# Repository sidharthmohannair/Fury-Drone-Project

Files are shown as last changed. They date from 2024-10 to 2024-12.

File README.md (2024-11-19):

# **Fury Drone Project**

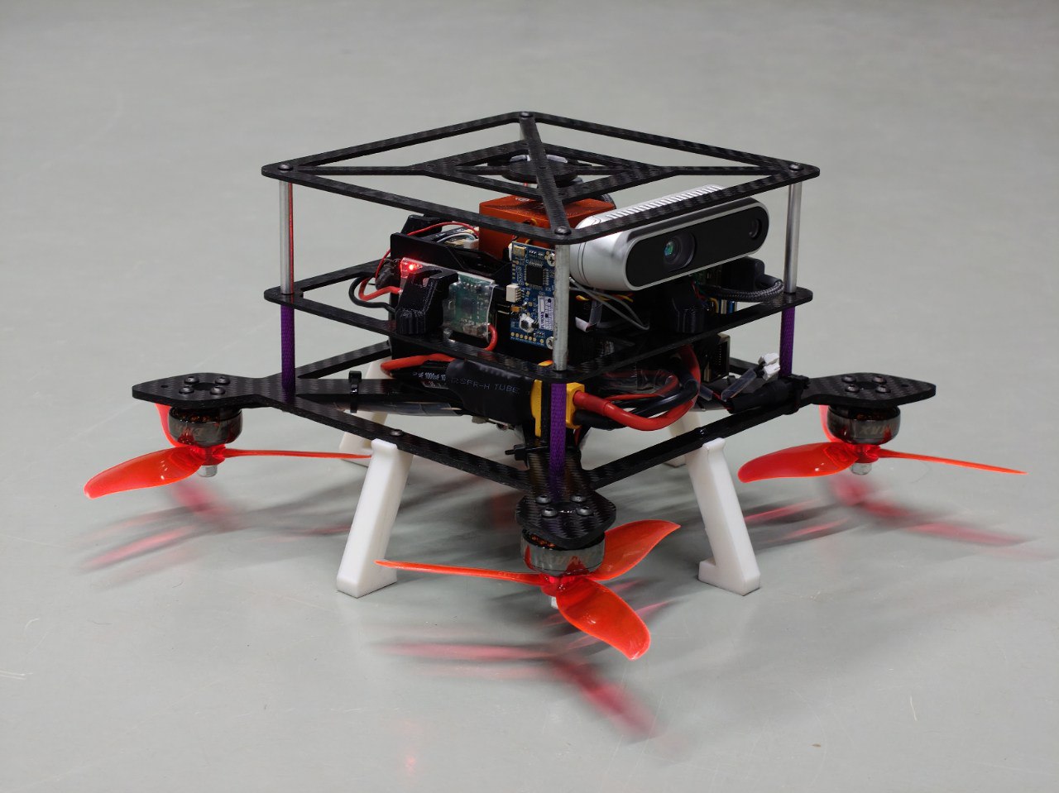
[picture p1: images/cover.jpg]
FuryVision AAV


Welcome to the **Fury Drone Project** repository! This project showcases the development of **Fury**, a high-performance, multi-mission **Autonomous Air Vehicle (AAV)** platform designed for various aerial missions, incorporating advanced sensors and components.

The repository contains everything you need to build, modify, and fly the **Fury Drone**, including design files, firmware, software, and documentation for multiple versions of the drone.

## **Overview**

The **Fury Drone** is engineered to push the boundaries of **unmanned aerial systems (UAS)** technology. It integrates components such as the **Pixhawk Orange Cube+ flight controller**, **Intel RealSense cameras**, **Emax brushless motors**, and **Here 3+ GPS module** for precise navigation and mission versatility.

This repository covers:
- **Original Fury Drone**: Developed as the core platform for high-performance UAS missions, the original version was designed by **SPIN Laboratory, Dept. of Electrical Engineering, IIT Kanpur**.
- **FuryVision AAV**: A modified version designed to accommodate **four Intel RealSense cameras** for enhanced visual and spatial sensing. This version was developed by the **Open Drone Team, CDOH Lab, ICFOSS, Thiruvananthapuram**, based on the requirements specified by IIT Kanpur.

---

## **Versions**

This repository contains two main versions of the Fury drone:

1. **Original Fury Drone**  
   - The foundational version of the Fury platform, designed for general high-performance UAS missions.
   - Developed by **SPIN Laboratory, Dept. of Electrical Engineering, IIT Kanpur**.
   - This version features basic flight capabilities using the **Pixhawk Orange Cube+** and standard UAS components.

2. [**FuryVision AAV**](/versions/2_furyvision_aav/README.md)  
   - An upgraded version of the Fury drone, modified to mount and integrate **four Intel RealSense cameras** for enhanced visual and spatial sensing.
   - Developed by the **Open Drone Team, CDOH Lab, ICFOSS, Thiruvananthapuram**, based on requirements specified by **IIT Kanpur**.
   - Includes advanced capabilities for visual sensing, spatial mapping, and autonomous navigation.

Each version has its own folder within the `versions/` directory, containing specific design files, firmware, and instructions.

---

## **Getting Started**

To get started with building and flying the **Fury Drone**, follow these steps:

### 1. **Clone the Repository**
   ```bash
   git clone https://github.com/sidharthmohannair/Fury-Drone-Project.git

   cd Furry-Drone-Project
   ```

### 2. **Choose a Version**
   Navigate to the version you're interested in:
   - For the original version: `versions/original_fury/`
   - For the modified version: `versions/furyvision_aav/`

### 3. **Follow the Setup Instructions**
   Refer to the detailed setup guides in the **`INSTALLATION.md`** and **`assembly_instructions.md`** files for each version.

### 4. **Upload Firmware**
   Upload the appropriate firmware for the version you’re working on. Check the **firmware/** directory for instructions.

---

## **Hardware Requirements**

The Fury drone is built using high-quality components to ensure robust performance. Some of the key hardware includes:

- **Flight Controller**: Pixhawk Orange Cube+
- **Motors**: Emax Brushless Motor, 2306-2400KV
- **GPS**: Here 3+ GPS Module
- **Cameras** (FuryVision AAV): Intel RealSense D435i
- **ESC**: Holybro Tekko 4in1 50A
- **Battery**: 14.8V, 2200mAh LiPo

A full Bill of Materials (BOM) is provided in the hardware directories for each version.

---

## **Testing and Logs**

Test data, including flight logs, motor thrust tests, and temperature data, can be found in the **`tests/`** directory. This folder includes logs from various performance evaluations and flight tests, which are critical for tuning and performance analysis.

---

## **Contributing**

We welcome contributions to the **Fury Drone Project**! If you'd like to contribute:
- Fork the repository.
- Create a new branch with your feature or fix.
- Submit a pull request for review.

Please read the [**CONTRIBUTING.md**](/CONTRIBUTING.md) file for detailed guidelines.

---

## **License**

This project is licensed under the **MIT License** – see the [**LICENSE.md**](/LICENSE) file for details.

---

## **Contact**

If you have any questions or need further assistance, feel free to reach out by opening an issue on GitHub.

---

### **Mission Statement**

The **Fury Drone Project** is more than just a platform—it's a symbol of innovation, collaboration, and the relentless pursuit of excellence in the field of unmanned aerial systems. Whether you're building, modifying, or flying Fury, we hope this project provides valuable insights and serves as a robust foundation for your journey in aerial autonomy.

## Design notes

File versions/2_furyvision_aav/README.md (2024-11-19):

# **FuryVision AAV - Version 2**

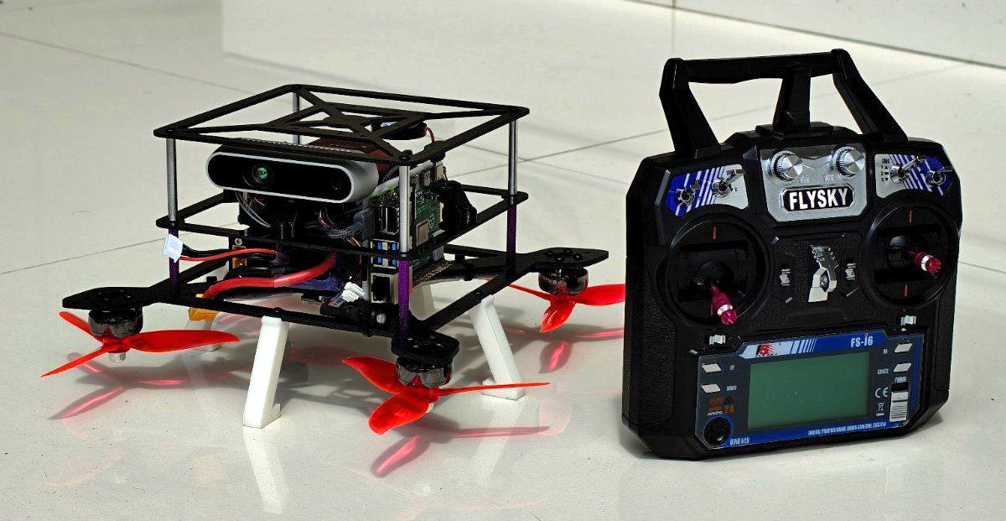
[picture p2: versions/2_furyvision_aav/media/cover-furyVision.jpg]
FuryVision AAV


## **Overview**
The **FuryVision AAV** is an advanced, multi-mission Autonomous Air Vehicle (AAV) designed for enhanced visual sensing and autonomous navigation. Built upon a custom carbon fiber frame, it integrates cutting-edge technologies such as **Intel RealSense cameras**, a **Pixhawk Orange Cube+ flight controller**, and a **Here 3+ GPS module**, making it ideal for missions requiring precise spatial mapping and navigation.

---

## **Core Specifications**

| **Component** | **Details** |
|---|---|
| **Frame** | Custom-designed carbon fiber frame, with 3D-printable parts included |
| **Motors** | Emax Brushless Motor, 2306-2400KV |
| **Propellers** | Tri Blade, 5.0*5.5 |
| **Flight Controller** | Pixhawk Orange Cube+ |
| **Radio Receiver** | X6B 2.4G 6CH i-BUS PPM PWM Receiver |
| **Battery** | 14.8V, 2200mAh LiPo |
| **All-Up Weight** | 1161g (frame, battery, 4 cameras) |
| **Weight (Without Battery)** | 923g (frame and cameras only) |
| **GPS/Compass (Optional)**| Here 3+ GPS module |
| **ESC** | Holybro Tekko 4in1 ESC (50A Continuous, 60A Burst, Supports 4-6S battery)  |
| **Companion Computer (Optional)** | Raspberry Pi 4, 8GB |
| **Firmware** | ArduCopter v4.5.6 (7ce11b41) |
| **Flight Time** | 8 minutes 40 seconds (all-up weight: 1161g, RTL voltage: 3.3V per cell) |
| **Cell Voltage** | Before: 16.15V, After: 13.5V |
| **Flight Modes** | Stabilize, Altitude Hold, Loiter |
| **Remote Controller Mapping** | Throttle (Ch3), Pitch (Ch2), Roll (Ch1), Yaw (Ch4), Modes (Ch5), Arm/Disarm (Ch6) |
| **Motor Temperatures (Post-Flight)** | Max: 50.1°C, ESC Max: 53.5°C |

---

## **Key Features**
- **Advanced Sensing**: Four Intel RealSense cameras for superior depth perception and obstacle detection.
- **Precision Navigation**: Here 3+ GPS and Pixhawk Orange Cube+ for accurate positional awareness.
- **Optimized Flight Performance**: Pre-configured firmware for stable operation across all flight modes.
- **Scalable Design**: Optional integration with a Raspberry Pi for advanced processing capabilities.

---

## **What’s Included**
- Custom frame and component designs ([STL](hardware/STL/) and [CAD](hardware/CAD/)).
- Pre-tuned parameters ([fury_drone1.param](firmware/fury_drone1.param)) for optimal performance.
- ROS integration support for RealSense cameras (coming soon).

---

## **Documentation**

- [Assembly Guide](/versions/2_furyvision_aav/docs/Assembly%20of%20FuryVision%20AAV.pdf)  
  Instructions for assembling the drone frame and components.

- [Installation Guide](docs/INSTALLATION.md)  
  Step-by-step guide for firmware installation, calibration, and setup.

- [Troubleshooting Guide](docs/TROUBLESHOOTING.md)  
  Solutions for common issues during assembly, configuration, and flight.

- [Performance Test Results](tests/performance_test_results.pdf)  
  `/tests` folder contains all test logs and performance metrics.

---

## **Basic Folder Structure**
```plaintext
furyvision_aav/
├── docs/
│   ├── README.md
│   ├── ASSEMBLY_GUIDE.md
│   ├── INSTALLATION.md
│   └── TROUBLESHOOTING.md
├── hardware/
├── firmware/
├── tests/
└── media/
```

---

## **Performance Highlights**
- **Flight Time**: 8 minutes 40 seconds with an all-up weight of 1161g.
- **Battery Performance**: Voltage dropped from 16.15V to 13.5V after flight.
- **Temperature**: Motors peaked at 50.1°C, ESC at 53.5°C after flight.

---

## **Next Steps**
1. Assemble the drone using the provided **Assembly Guide**.
2. Install the firmware and calibrate sensors with **Mission Planner** as described in the **Installation Guide**.
3. Refer to **Troubleshooting** for resolving any issues during setup or flight.

---

## **FuryVision AAV in Action**
FuryVision AAV flying

---

## **Contributing and Feedback**
- For issues or feature requests, please open an issue on our [GitHub Issues](https://github.com/sidharthmohannair/Fury-Drone-Project/issues) page.
- Contributions are welcome! Refer to [CONTRIBUTING.md](/CONTRIBUTING.md) for guidelines.

---

## **License**
This project is licensed under the [MIT License](/LICENSE). You’re free to use, modify, and distribute it under the terms of the license.

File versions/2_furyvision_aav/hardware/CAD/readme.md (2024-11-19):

## Frame Design Information
For modification download the file **furyvision_aav.step (.step file)** then import to your cad software(eg. Fusion 360, Onshape) then you can modifiy every parts of the Drone. Verify the bottom, middle, and top plates' side-to-side and corner-to-corner measurements while making design changes. For a seamless assembly, make sure each screw hole is machined in accordance with the chosen components. 

You can find the fully assembled file on `versions/2_furyvision_aav/hardware/CAD/furyvision_aav.step`

### Parts:

- Bottom Plate
- Middle Plate
- Top Plate
- RasberryPI Mount
- Power module mount
- Cam Mount
- Landing Gear
- Flight controller holder 
 
### Carbon Fiber Plate Thickness:

- Base Plate: 4mm thick carbon fiber
- Middle Plate: 2mm thick carbon fiber
- Top Plate: 2mm thick carbon fiber

The .dxf files for each part can be found in the 'versions/2_furyvision_aav/hardware/CAD' folder, and are ready for carbon fiber cutting.

### Parts Made using 3D Printing
- Raspberry Pi 4 mount 
- Power module mount
- Cam Mount 
- Landing Gear
- Flight controller holder

The .stl files for 3D Printing parts can be found in the 'versions/2_furyvision_aav/hardware/STL/'folder

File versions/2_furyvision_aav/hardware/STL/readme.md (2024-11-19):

## 3D Printing Parts Information
You can find all the 3D printing parts in the `versions/2_furyvision_aav/hardware/STL/` folder.

- Raspberry Pi 4 mount 
- Power module mount
- Cam Mount 
- Landing Gear
- Flight controller holder

The parts are designed to be printed in PLA with an infill of 60% for optimal strength and durability.

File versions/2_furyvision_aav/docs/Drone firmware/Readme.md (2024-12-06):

# How to Upload/Upgrade Drone Firmware Using Mission Planner Software

**Mission Planner** is a free software tool widely used for drones and other autonomous vehicles. It helps you manage, program, and monitor missions, including updating your drone's firmware to ensure optimal performance. 

## Requirements
- A Windows PC with Mission Planner installed
- Assembled drone or its flight controller
- USB cable

>Note: Firmware updates via Mission Planner are only supported on Windows OS.

## Steps to upload/upgrade Firmware

### Preparation

- **Remove Propellers**: Always remove the drone's propellers before powering it up to ensure safety.

- **Check Power Source**: While updating firmware, the USB connection is usually sufficient. A battery is not mandatory unless specifically required for your flight controller. 

---

### Steps

 1. **Open Mission Planner** : Launch the Mission Planner software on your Windows PC.

	Open Mission Planner

 2. **Connect the Flight Controller** : Use a USB cable to connect the flight controller to your computer.
 	>Tip:  Ensure the USB cable is securely connected to avoid interruptions during the update.

 3. **Check COM Port**: 
 - In Mission Planner, locate the available **COM port**.
 - Select the correct port and configure the **baud rate** (usually set to **115200**).

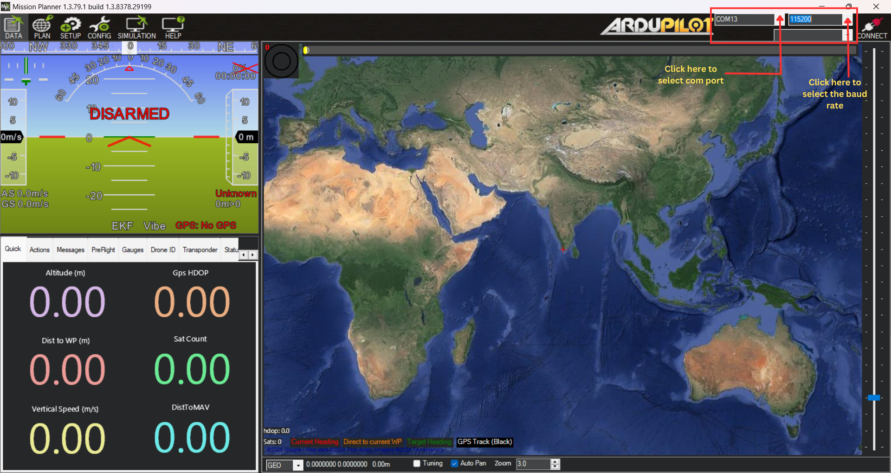
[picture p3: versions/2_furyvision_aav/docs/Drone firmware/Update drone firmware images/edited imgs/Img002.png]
Select port and baud rate
	

 4. **Do Not Click Connect**: **Do not click** the **Connect** button in Mission Planner during this process.

	Do not click Connect

 5. **Navigate to Firmware Installation**: Go to **Setup** → **Install Firmware** → Choose the desired drone type (Quadcopter, Hexacopter, etc.).

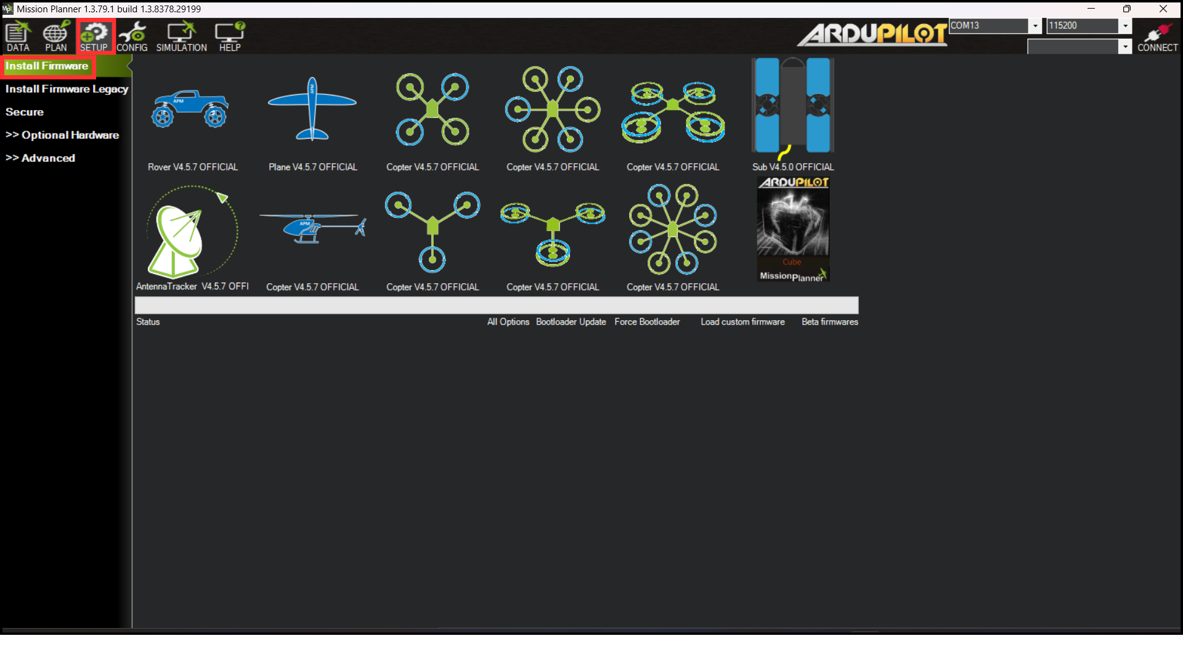
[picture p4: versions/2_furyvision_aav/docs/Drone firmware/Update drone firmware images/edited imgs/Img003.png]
Select Setup tool
	

6. **Confirm Firmware Version**:
A popup will display the available firmware version. Click Yes to proceed.

	Cofirm to Update firmware version

7. **Select the Platform**: Use the dropdown menu to select the appropriate flight controller for your drone (e.g., Pixhawk, Cube Orange).

	Select Flight controller
	 
8. **Upload Firmware**:
- Click to upload the firmware.
- Follow the on-screen instructions carefully to avoid errors.

	Click to upload firmware
9. **Follow the Instruction**: Carefully read and follow any additional popup messages for specific instructions during the process.

	Popup Message

10. **Wait for Upload to Complete**:
Allow the upload process to finish without interruptions.

	Processing

11. **Completion**:

- Once the update is complete, Mission Planner will display an "Upload Done" message.
- The flight controller will emit a beep sound to confirm the update.

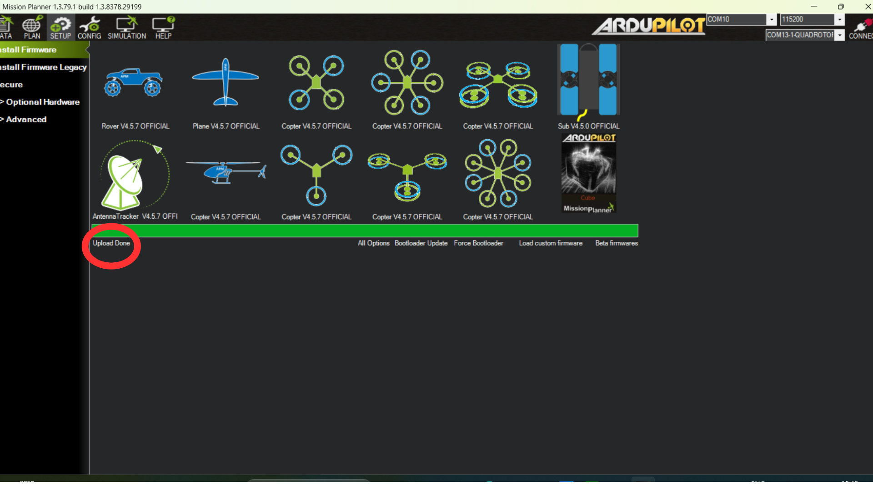
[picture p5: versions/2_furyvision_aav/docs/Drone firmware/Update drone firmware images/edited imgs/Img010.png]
Upload Done
	
	
12. **Reboot the Flight Controller**:
Reboot the flight controller to apply the firmware update.
	
---

### Post-Update Tips
- Check the firmware version on your flight controller to ensure it matches the one you uploaded.
- Perform a basic system check to confirm all sensors and components are functioning correctly.
- If required, recalibrate sensors (e.g., accelerometer, compass).	
---
## Your firmware update is now complete!

Enjoy improved performance and new features on your drone. For further assistance, refer to the Mission Planner documentation or support forums.

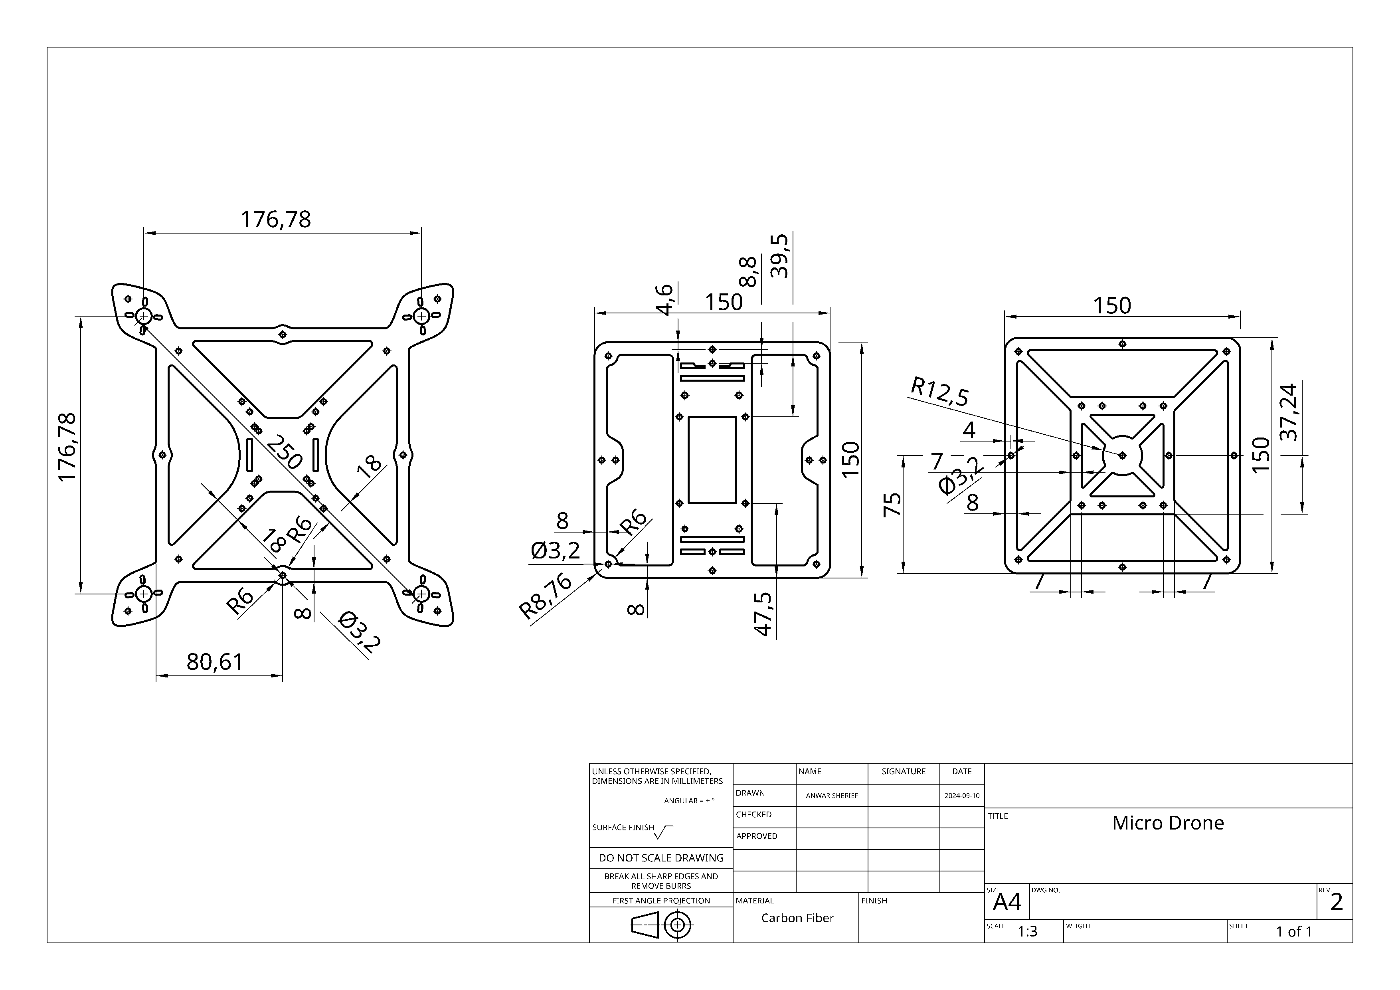
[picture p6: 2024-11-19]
versions/2_furyvision_aav/hardware/CAD/CF_Frame_Dimensions.png

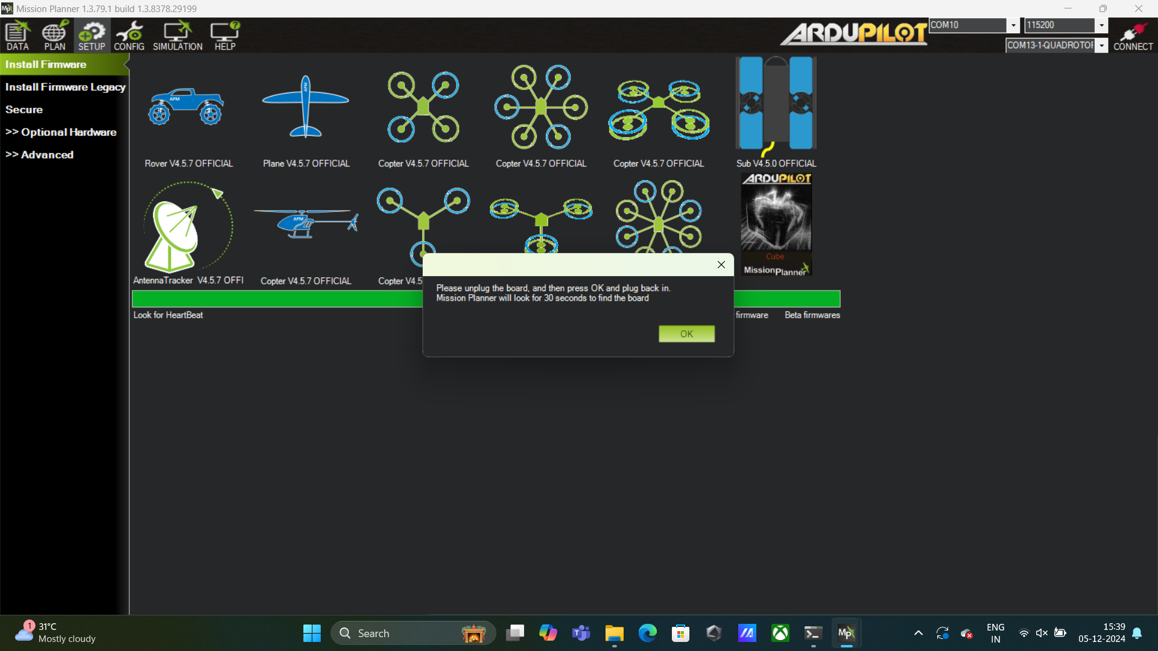
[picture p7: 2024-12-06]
versions/2_furyvision_aav/docs/Drone firmware/Update drone firmware images/FW8.png

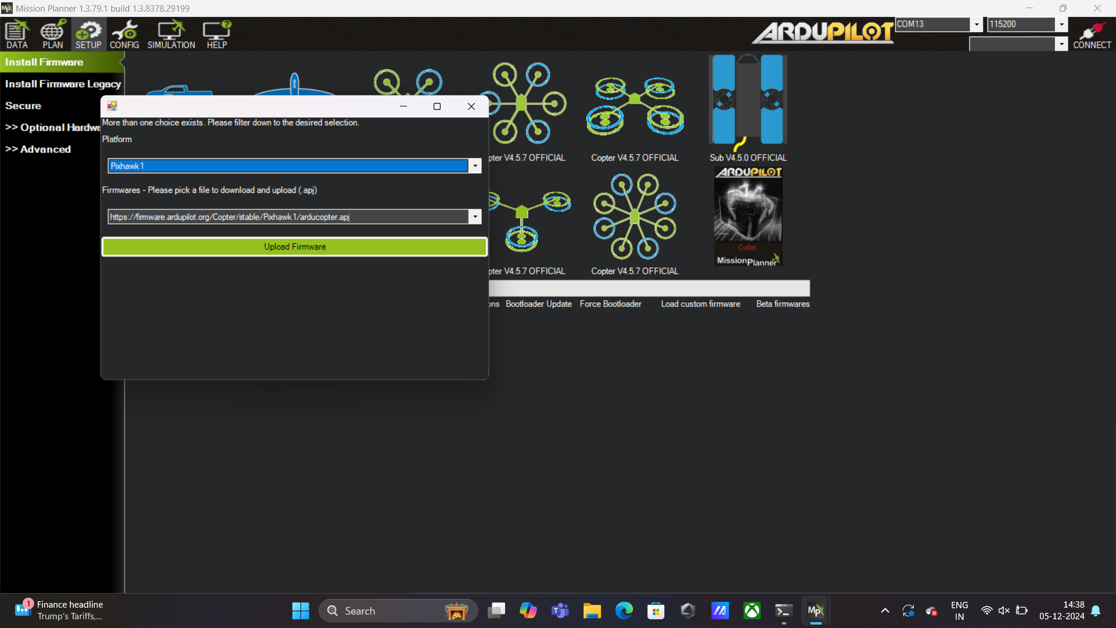
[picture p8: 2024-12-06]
versions/2_furyvision_aav/docs/Drone firmware/Update drone firmware images/FW7.png

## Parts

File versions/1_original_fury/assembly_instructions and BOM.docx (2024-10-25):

# Components List and Assembling Instructions

Material:

1. The layered design consists of a Base(4mm thick), Middle, and top(2.5mm thick) layer frame made of carbon fiber.

# 2. Electronic Speed Controller (https://robu.in/product/holybro-tekko32-f4-4in1-50a-esc/?gad_source=1)Holybro Tekko32 F4 4in1 50A ESC (https://robu.in/product/holybro-tekko32-f4-4in1-50a-esc/?gad_source=1)

3. Flight controller pixhawk orange cube (https://robu.in/product/hex-pixhawk-cube-flight-controller-autopilot/?gad_source=1)

# 4. EMAX Pulser LED Motor or EMAX RS2205 2300KV Brushless DC Motor for FPV Racing Drone - Red Cap (CCW Motor Rotation) X4 (https://www.electronicscomp.com/emax-rs2205-2300kv-brushless-dc-motor-for-fpv-racing-drone-red-cap-ccw-motor-rotation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)

5. GenX 14.8V 4S 2200mAh 40C / 80C Premium Lipo Lithium Polymer Battery (https://robokits.co.in/batteries-chargers/genx-power-premium-lipo-battery/genxpower-14.8v-lipo-batteries/genx-14.8v-4s-2200mah-40c-80c-premium-lipo-lithium-po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)

# 6. Raspberry Pi 4 Model-B with 8 GB RAM (https://robu.in/product/raspberry-pi-4-model-b-with-8-gb-ram/?gad_source=1)

# 7. Receiver: X6B 2.4G 6CH i-BUS PPM PWM AFHDS (https://robu.in/product/x6b-2-4g-6ch-bus-ppm-pwm-receiver-afhds/)

# 8. UBEC: HENGE 8A Output 5V / 6V 6A / 8A Max 12A Inport 7V-25.5V 2-6S Lipo / 6-16 Cell Ni-Mh Input Switch Model BEC for RC Drone (https://www.amazon.com/HENGE-Output-Inport-7V-25-5V-Switch/dp/B0868NXP1V)

## 9. Power Brick Mini for Cube Orange autopilot (https://gadgetsdeal.in/shop/pixhawk-cube-pilot/pixhawk-2-mini-power-brick-power-module-in-india/)

# 10. Fan Shim for Raspberry PI (https://robu.in/product/raspberry-pi-cooling-fan-shim/)

11. Data cable for connecting Raspberry Pi to power brick (https://www.amazon.in/gp/product/B08CF3D7QR/ref=ox_sc_act_title_3?smid=A1WYWER0W24N8S&th=1)

# 12. SanDisk Extreme 64GB microSDXC UHS-I, Raspberry pi. (https://www.amazon.in/SanDisk-Extreme-microSD-Smartphones-Action/dp/B0B2DDJGF8?th=1)

# 13. 30cm Lipo Battery Strap Belt Reusable Cable Tie Wrap (https://robu.in/product/30cm-lipo-battery-strap-belt-reusable-cable-tie-wrap/)

14. Mountable XT60 connector (https://roboticsdna.in/product/xt60e-m-male-plug-connector/?src=google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)

# 15. Orange HD 5055(5X5.5) Tri Blade Flash Propellers 2CW+2CCW 2 Pair Clear Blue (https://robu.in/product/orange-hd-50555-0x5-5-tri-blade-flash-propellers-2cw2ccw-2-pair-clear-blue/)

16. Two separation plates plate 1 for mounting the Raspberry Pi and plate 2 for the mounting power brick, receiver, and ubec.

# 17. JST Male 2 Pin Connector-10pcs (https://robu.in/product/jst-male-2-pin-connector-set-10pcsset/)

18. 3D printed spacers.

# Assembly:

Step: 1 First, we need to assemble the base frame( carbon fiber plate 4.00mm).

Step: 2 Then, we need to attach the Emax motor on each of the four arms using M3 (6mm) screws.

Step: 3 Each motor has three wires that go to the ESC terminal because there are 12 terminals total—three for each motor—in the Tekko 4 in one ESC. separately solder each wire in M1, M2, M3 and M4 terminal. For terminals you can refer to the picture below

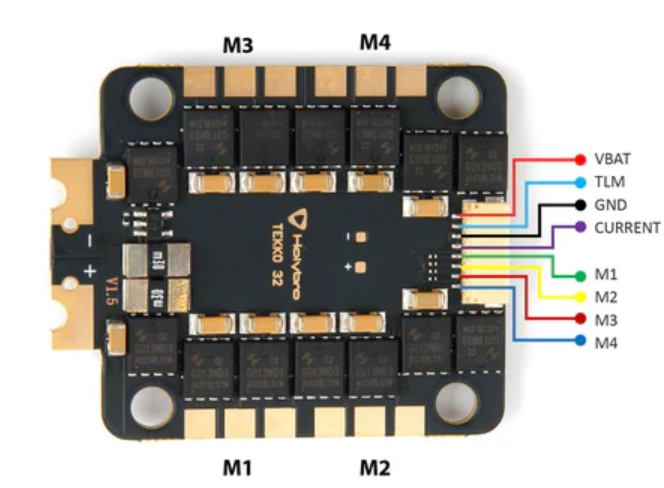
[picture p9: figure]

# Step 4: Then take the Raspberry Pi mount plate and insert the M3 nut insert( 4mm length) into the mounting hole for Raspi.

# Step: 5 On the Raspberry Pi 4 model attach the fan shimp( cooling fan) in the Raspberry Pi.

# Step: 6 Then mount it in the Raspberry Pi base plate(refer image given),

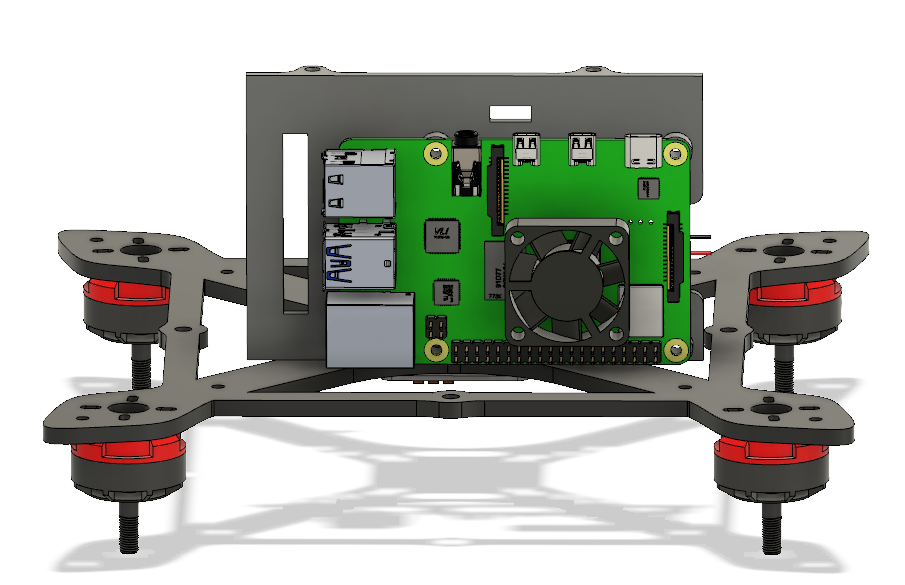
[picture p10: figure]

# Similarly, we have to mount the component in the Electronics base plate but before that, we have to make a customized power module,

Customization of Power Module for Safe Battery Power Distribution:

Step: 8

Preparation: Begin by carefully removing the connectors at both ends of the power module, ensuring precise handling to avoid damage to internal components.

Step: 9

Selection of XT60 Connector: Select an XT60 connector suitable for the power requirements of the Fury_4 drone, taking into account factors such as current rating and compatibility with existing wiring

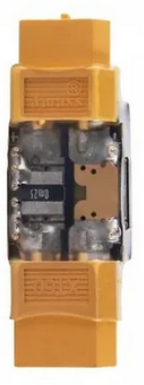
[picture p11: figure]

Step: 10

Soldering Procedure: With meticulous attention to detail, solder the XT60 connector to the power module, and also solder the red and black wire of jst 2 pin connector (https://robu.in/product/jst-male-2-pin-connector-set-10pcsset/)( for separate power supply for raspberry pie) into the positive and negative terminal adhering to correct polarity to prevent electrical damage and ensure compatibility with standard battery connectors.

Step: 11
Inspection and Testing: Thoroughly inspect the solder joints for proper connection and integrity, verifying polarity alignment and continuity. Conduct comprehensive testing to validate the functionality and safety of the customized power module before integration into the drone assembly.

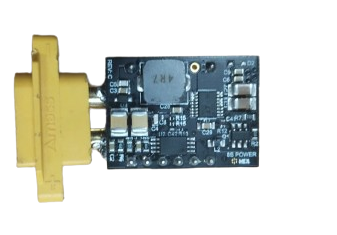
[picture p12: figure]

Step12:

Once the power module has been customized with the XT60 connector, the next step is to integrate it with the UBEC (Universal Battery Eliminator Circuit). This critical component plays a pivotal role in regulating voltage levels and providing clean, stable power to the electronic systems of the Fury drone

Step:13(optional)

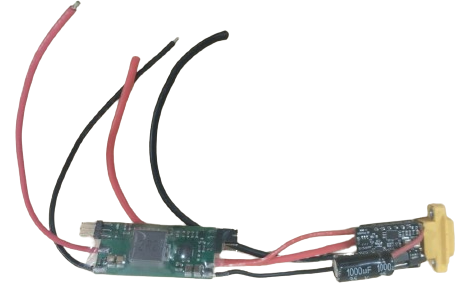
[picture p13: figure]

In the above image, you can see the capacitor is also attached to the power brick capacitor has a major role in it

Role of Capacitors in ESCs:

- Noise Reduction: Capacitors filter out electrical noise generated by ESCs and motors, ensuring a clean power supply to other components.
- Voltage Stabilization: Capacitors stabilize voltage output, preventing voltage fluctuations that could affect motor performance or damage electronics.
- Protection: Capacitors protect ESCs and other components from voltage spikes and surges by absorbing excess energy.
- The primary use of a capacitor to store the electrostatic energy in an electric field and supply this energy whenever possible to the circuit.

Step 14:

After customizing the power brick we can attach the component to the electronics base plate needed to be installed on the carbon fiber main body.

Step: 16 Then we have to mount the middle frame of carbon fiber (2mm Thickness) with the help of the M3 (35mm)spacers (https://www.quadkopters.com/product/hardware-and-accessories/m335-aluminum-spacers-with-grip/)mount the middle frame of carbon fiber plate with 8 M3 (35mm)spacers after it will look like this as it is shown in the below image

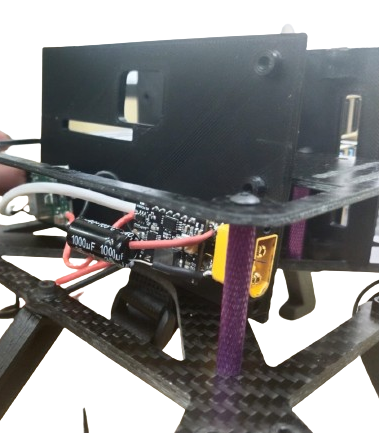
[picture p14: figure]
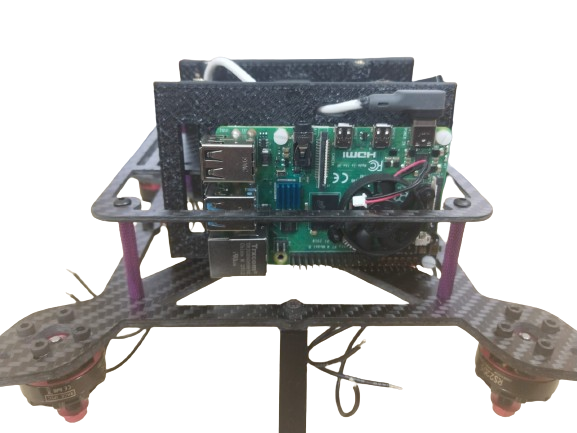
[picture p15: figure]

Step: 17

In the image we can see we passed a USB cable that cable is customizable we removed the end of the USB cable connecter,

Step: 18 Connect the red and black wire we get after removing the connecter,

Step: 19 Connect negative(black) and positive(red) wires to both terminals of the UBEC output terminal also keep its polarity as it required do not interchange the wire it might damage the component

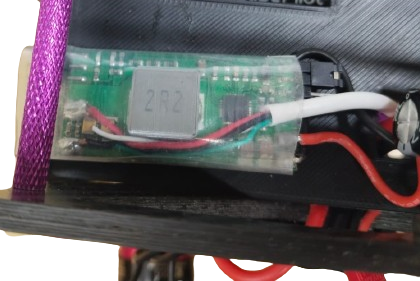
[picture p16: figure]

Some usb have green and white wire that we have to cut also we have to be careful with both green and white wire while powering they should not touch it would be better to cut them.

Step: 20 Also mount the RC Receiver (https://robu.in/product/x6b-2-4g-6ch-bus-ppm-pwm-receiver-afhds/) using a M2 x 8mm screw as shown in the image.


The receiver is mounted on electronic component mounting plate in the top right corner

Step: 21 Mount the pixhawk in the middle of both electronic component and raspberry pi plates on 2nd middle carbon fiber plate as it shown in the below image


We can use double-sided tape to stick the flight controller on the carbon fiber plate

Step: 22 Now we have to mount the ESC in the bottom frame (base frame) and keep the connection inside it will be easy to mount the ESC with the frame.

Step: 23 Solder the wire of positive and negative coming from the power module in the front


positive and negative terminal.

Step: 24 Mount the ESC by keeping a gap of 10mm from the carbon fiber main body to avoid electrical contact. Use a M3x12mm nylon standoff for this, and tighten using a nylon nut from the top.

Step: 25 Connect the ppm Port situated on the RC receiver to the pixhawk RC In port with the receiver cable.

Step: 26 Connect the in-power module to pixhawk (power 1 port) using the cables that comes with the power brick.

Step: 27 Connect the ESC and Pixhawk for the motor wiring( Motor 1, 2, 3, 4 to pixhawk’s mains out 1,2,3,4 corresponding) and connect the ground pin from ESC to any free ground on Pixhawk’s main out(refer to images below)


Step 28: After this mount the final carbon fiber plate( 2mm) with the help of 3D printed spacers( as shown in the below image with white color)by using the M3 screws (40mm)


Step:29 connect the GenX 14.8V 4S 2200mAh 40C / 80C Premium Lipo Lithium Polymer Battery (https://robokits.co.in/batteries-chargers/genx-power-premium-lipo-battery/genxpower-14.8v-lipo-batteries/genx-14.8v-4s-2200mah-40c-80c-premium-lipo-lithium-po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)

Step: 30 Do all the necessary calibrations such as accelerometer, compass, and radio calibration. for more info visit the link below

https://ardupilot.org/copter/docs/esc-calibration.html

Step: 31 Verify the direction of the motor as the right (right from the direction of the face) and its diagonal should be the same (counterclockwise) and the rest should be clockwise. Also, remove the propellers while performing the ESC calibration,
These directions are done for our purposes; you can set directions to your specific requirements. If any motor is rotating in the wrong direction we have to swap any two wires out of 3 of that motor and the direction will be fixed for more info visit the below link

Motor: https://ardupilot.org/copter/docs/connect-escs-and-motors.html

Step 32: Mount the propeller in the motor (5X5.5 inches) considering the rotational directions.

Thank you for exploring the Fury drone documentation! We hope this comprehensive guide has provided valuable insights into the capabilities and design of this high-performance, multi-mission Autonomous Air Vehicle (AAV). As you continue your journey in the world of unmanned aerial systems, remember that Fury is more than just a machine—it represents innovation, collaboration, and the pursuit of excellence.

# Connections:


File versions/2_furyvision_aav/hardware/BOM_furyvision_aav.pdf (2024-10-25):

Component; Category; Component Name; Specifications/ Notes; Quantity Supplier; Unit Price; (INR); Total Price (INR); Frame; Carbon fiber - base plate; Thickness: 4mm; Link; carbon fiber - middle plate; Thickness: 2mm; carbon fiber - Top plate; Motors; Emax Brushless Motor; 2306-2400KV, hole pattern: 19 X 19; ESC; Holybro Tekko 4in1 ESC; Current 60A x4, Supports 4-6S battery; Propellers; Tri Blade Flash Propellers; 5.0*5.5, 2CW+2CCW 2 Pair; Flight Controller; Hex Pixhawk Cube; connectors; link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

Continuous Current 50A x4, Burst

Model: HX4-06222, Input voltage: 3.3 V /
5 V, I2C interface: 2, PWM I/Os: 14,
GPS/Serial interfaces: 4
up to 8s 30A continuous, XT60

Power Brick Mini

Capacity: 2200mAh, Nominal Voltage:
14.8V, Configuration: 4S1P, Discharge
Rate: 40C
Cost-effective high precision positioning,
L1 band RTK support with centimeter
level positioning accuracy, Equipped
with STM32H757 high
performance processor running real time
Bandwidth (KHz): 500, RF Range (GHz):
2.40 ~ 2.48, No. of channels: 6,
Transmitting Power: ≤ 20dBm.
Channels: 6(PWM), 8(PPM), 18(i-BUS)
Model, DSC port: PPM/PWM/i-BUS,
Range: >300m
Integrated 2 switch control LED and FPV

Premium Lipo Lithium Polymer Battery

Here 3+ – CAN GPS with in India

FlySky FS-i6 2.4G 6CH PPM RC Transmitter

PPM PWM Receiver

30mm 5V, Compatible with Raspberry Pi
Depth frame rate:Up to 90 fps, Depth
output resolution:Up to 1280 × 720,
Depth Field of View (FOV):87° × 58°,
RGB sensor FOV (H × V):69° × 42°,
RGB frame resolution:1920 × 1080
Color: Red, Type: Male, Pack of 10 male

Cooling Fan for Rpi

Intel Real SenseDepth Camera

JST Male 2 Pin Connector

Miscellaneous; Brass Threaded Round Insert; M3 X 6 mm -25 Pcs.; Link; M3 X 4 mm -25 Pcs.; Male to Female Nylon Hex Spacer; M3*6 mm - 10pcs; White nylon nut; M3 pack-25; Head Style: Countersunk Head; wrench.; Stand off Spacer; M3*3.5, Aluminium; Brass Heat Set Threaded Round Insert Nut; M2.5 X 5 mm -25 Pcs.; Silicone Wire; Red: 3m; Black: 3m; UHS-I, V30, 170MB/s Read,80MB/s; Write; Type-C Cable; Charging 3A Type-C Cable 1.2Meter; Spacer; M3*45mm 5pcs, female to male; 3D printed parts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

Type: M2.5 (2.5mm Diameter), Material:
Stainless Steel, Bolt Length: 8mm, Bolt
Material: Mild Steel, Brand: EasyMech,
Type: M3 (3mm Diameter), Bolt Length:
8mm, Easy Tighten with an Allen-style

Philips Head bolt

HT Socket Button Head Cap Allen Bolt

High Temperature Super Flexible Grade,

SanDisk Extreme 64GB microSDXC

Material: Nylon, Length: 30 CM, Width:

Lipo Battery Strap

Product model: XT60E-M, Metal
material: gold-plated, Instantaneous
current: 40A, Rated current: 20A
Portronics Konnect L POR-1081 Fast

XT60E-M Male Plug Connector

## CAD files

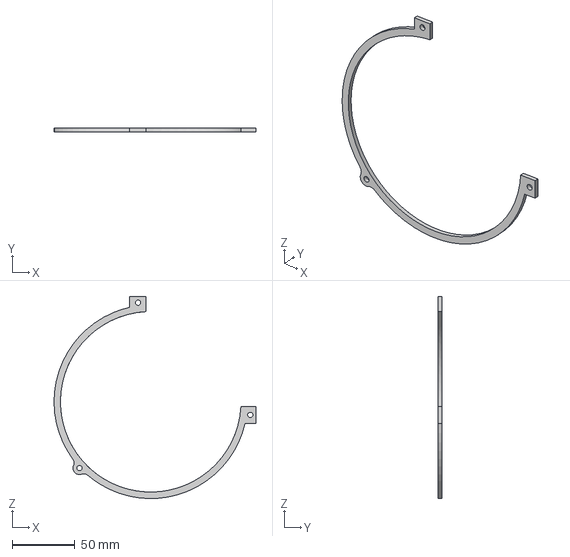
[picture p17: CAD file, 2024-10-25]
versions/1_original_fury/design/3D Models/proppler gaurd plate new design v17.iges
161.1 x 3.00 x 161.2 mm

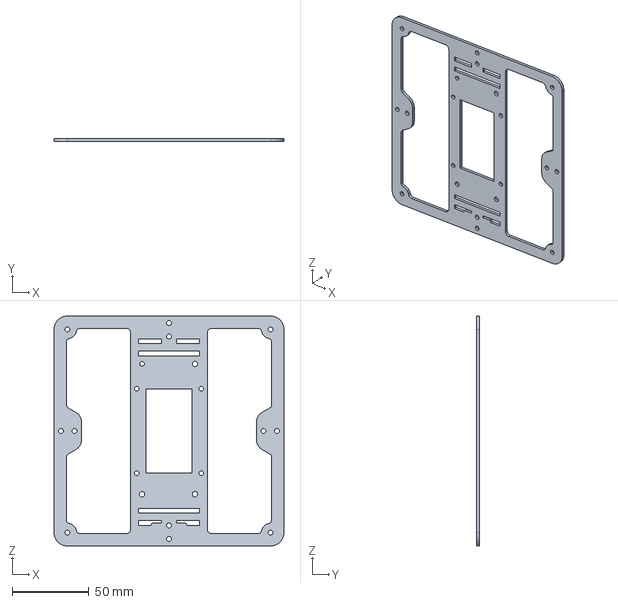
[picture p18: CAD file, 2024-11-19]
versions/2_furyvision_aav/hardware/CAD/Middle Plate.step
150.0 x 2.00 x 150.0 mm

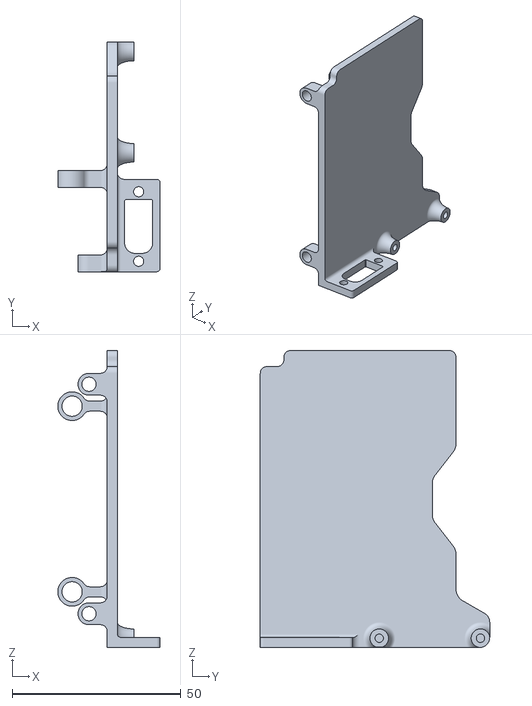
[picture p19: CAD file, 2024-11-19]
versions/2_furyvision_aav/hardware/STL/Power module Mount.stl
30.4 x 68.0 x 88.0

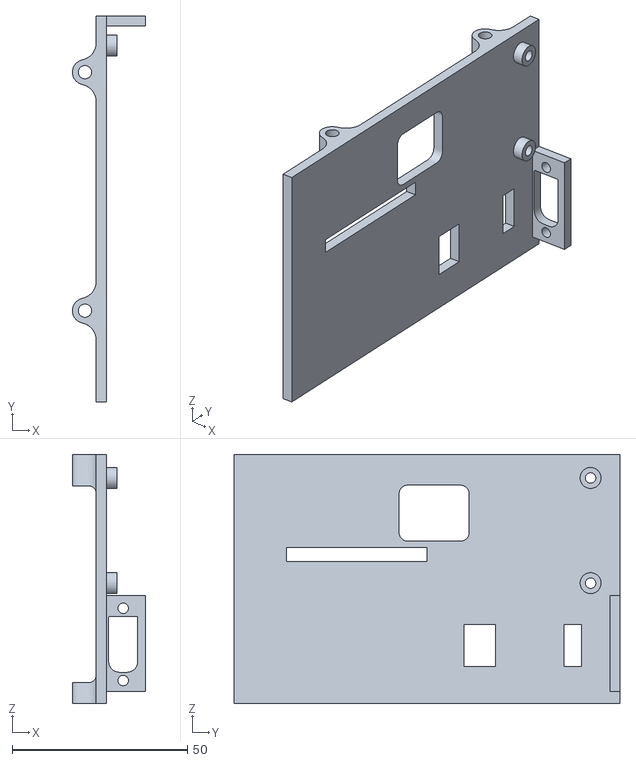
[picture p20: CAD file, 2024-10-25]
versions/1_original_fury/design/3D Models/electronics mount plate.stl
20.9 x 110.0 x 71.0

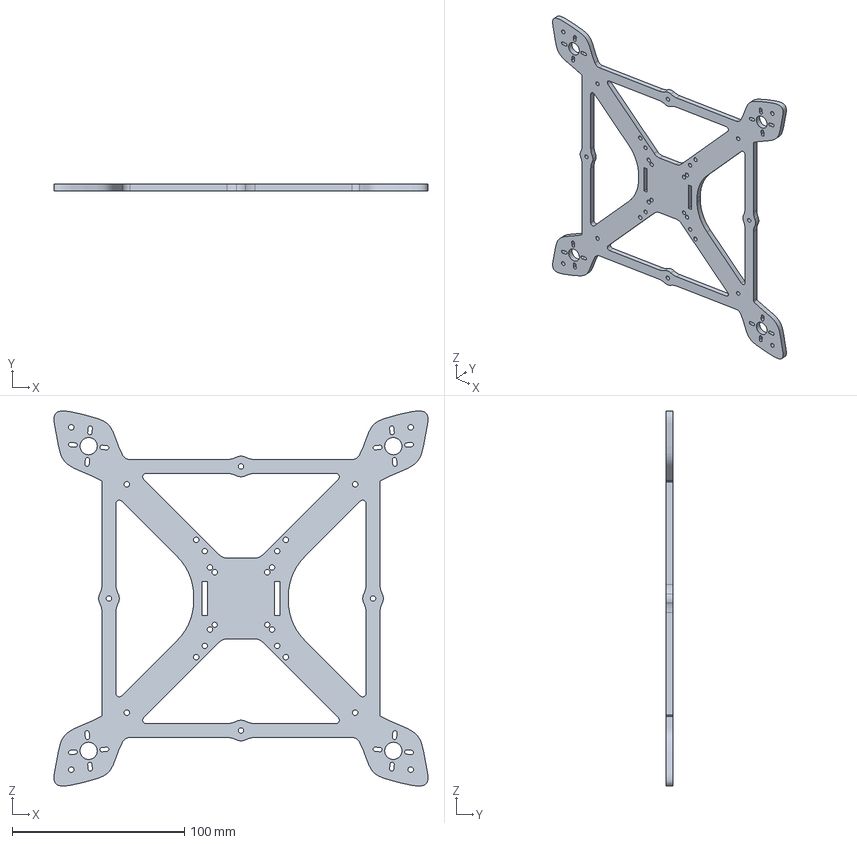
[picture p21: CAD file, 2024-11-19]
versions/2_furyvision_aav/hardware/CAD/Base Plate.step
217.0 x 4.00 x 217.6 mm

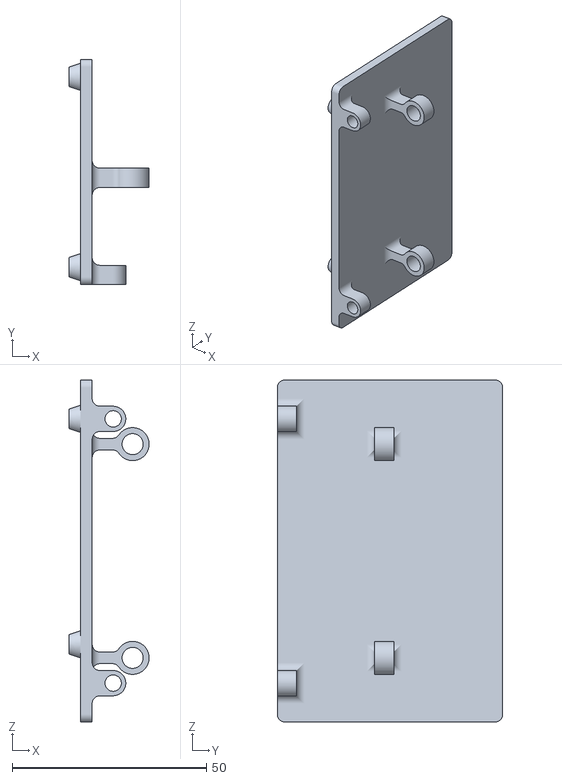
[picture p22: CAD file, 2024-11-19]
versions/2_furyvision_aav/hardware/STL/Raspberry Pi 4 mount .stl
20.6 x 58.0 x 88.0

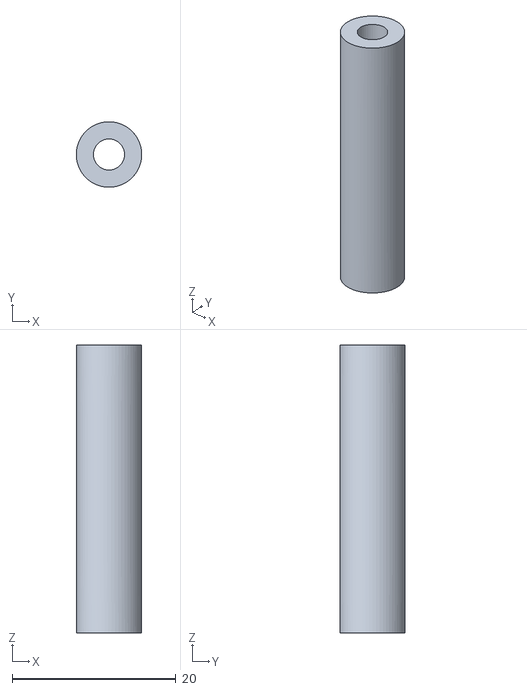
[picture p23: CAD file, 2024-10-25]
versions/1_original_fury/design/3D Models/PLA spacer for final carbon fibre plate.stl
8.00 x 8.00 x 35.2

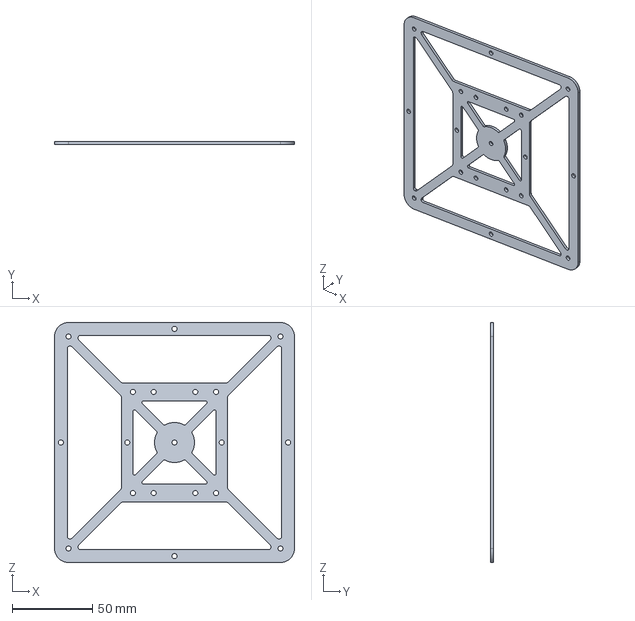
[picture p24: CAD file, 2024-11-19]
versions/2_furyvision_aav/hardware/CAD/Top Plate.step
150.0 x 2.00 x 150.0 mm

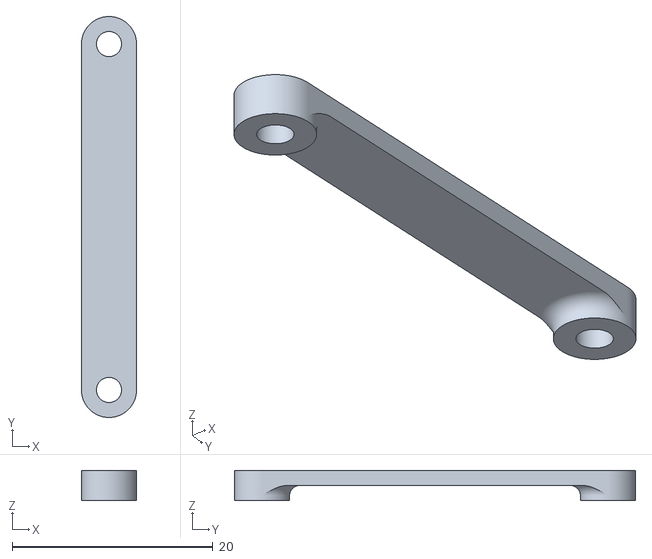
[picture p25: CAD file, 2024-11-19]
versions/2_furyvision_aav/hardware/STL/Flight controller holder.stl
5.50 x 40.0 x 3.00

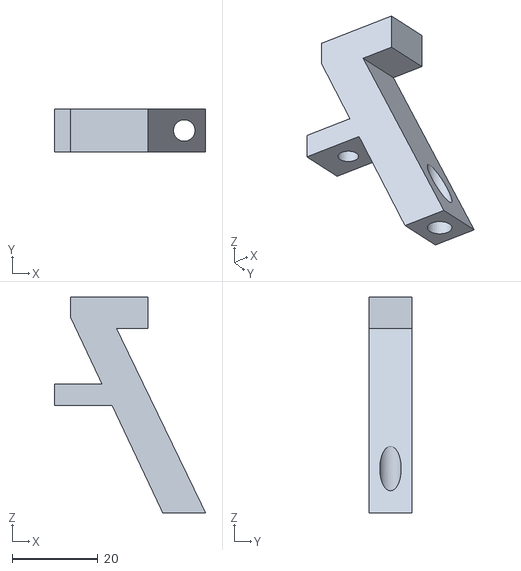
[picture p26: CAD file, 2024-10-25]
versions/1_original_fury/design/3D Models/Landing_Gear_Prototype.stl.stl
35.3 x 10.0 x 50.3

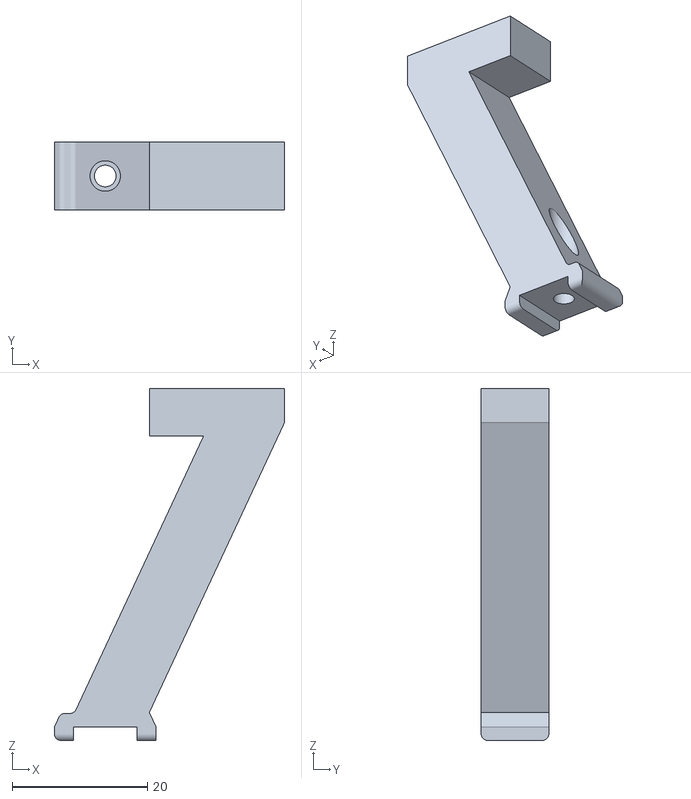
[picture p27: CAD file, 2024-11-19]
versions/2_furyvision_aav/hardware/STL/Landing Gear.stl
34.0 x 10.0 x 52.0

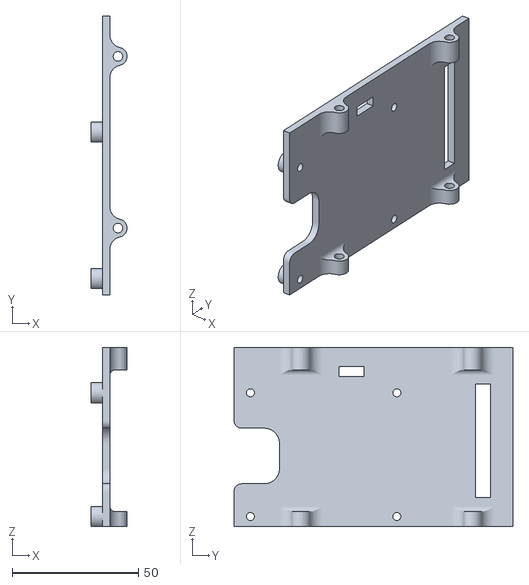
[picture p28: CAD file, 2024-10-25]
versions/1_original_fury/design/3D Models/raspberry pi mounting plate.stl
14.3 x 110.5 x 71.0

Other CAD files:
versions/2_furyvision_aav/hardware/CAD/Base Plate.dxf
versions/2_furyvision_aav/hardware/CAD/Middle Plate.dxf
versions/2_furyvision_aav/hardware/CAD/Top plate.dxf

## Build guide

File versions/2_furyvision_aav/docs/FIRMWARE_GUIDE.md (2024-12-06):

# How to Upload/Upgrade Drone Firmware Using Mission Planner Software

**Mission Planner** is a free software tool widely used for drones and other autonomous vehicles. It helps you manage, program, and monitor missions, including updating your drone's firmware to ensure optimal performance. 

## Requirements
- A Windows PC with Mission Planner installed
- Assembled drone or its flight controller
- USB cable

>Note: Firmware updates via Mission Planner are only supported on Windows OS.

## Steps to upload/upgrade Firmware

### Preparation

- **Remove Propellers**: Always remove the drone's propellers before powering it up to ensure safety.

- **Check Power Source**: While updating firmware, the USB connection is usually sufficient. A battery is not mandatory unless specifically required for your flight controller. 

---

### Steps

 1. **Open Mission Planner** : Launch the Mission Planner software on your Windows PC.

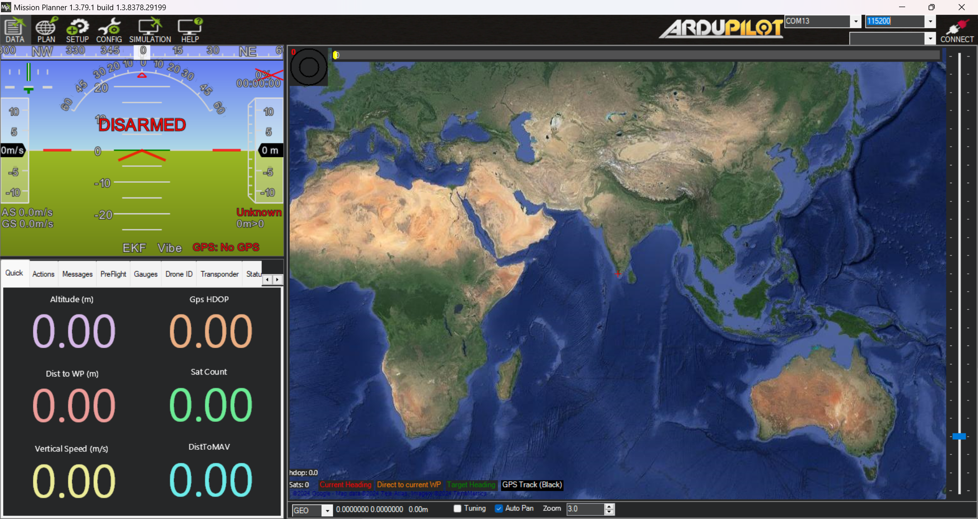
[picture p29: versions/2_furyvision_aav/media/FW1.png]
Open Mission Planner
	

 2. **Connect the Flight Controller** : Use a USB cable to connect the flight controller to your computer.
 	>Tip:  Ensure the USB cable is securely connected to avoid interruptions during the update.

 3. **Check COM Port**: 
 - In Mission Planner, locate the available **COM port**.
 - Select the correct port and configure the **baud rate** (usually set to **115200**).

	Select port and baud rate

 4. **Do Not Click Connect**: **Do not click** the **Connect** button in Mission Planner during this process.

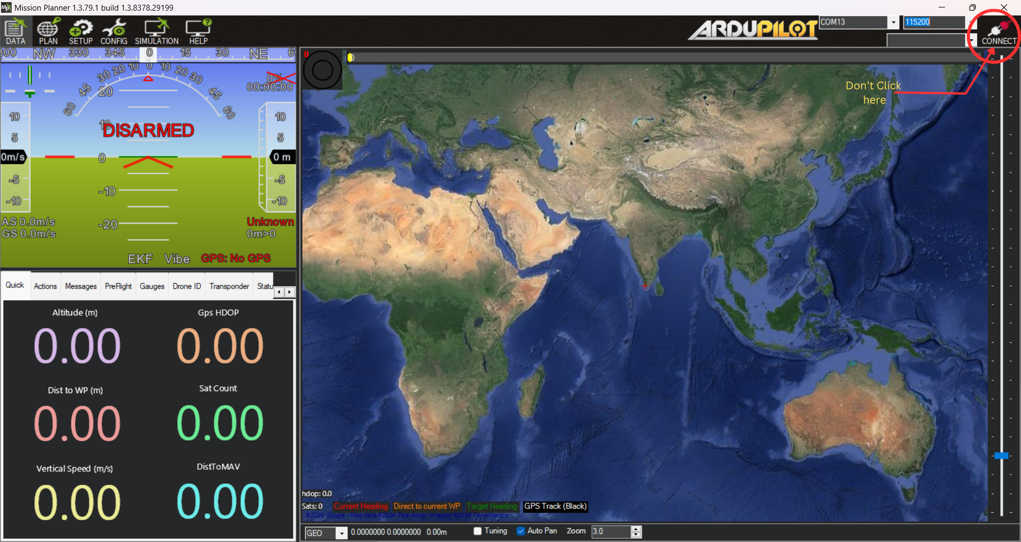
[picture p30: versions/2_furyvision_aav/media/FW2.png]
Do not click Connect
	

 5. **Navigate to Firmware Installation**: Go to **Setup** → **Install Firmware** → Choose the desired drone type (Quadcopter, Hexacopter, etc.).

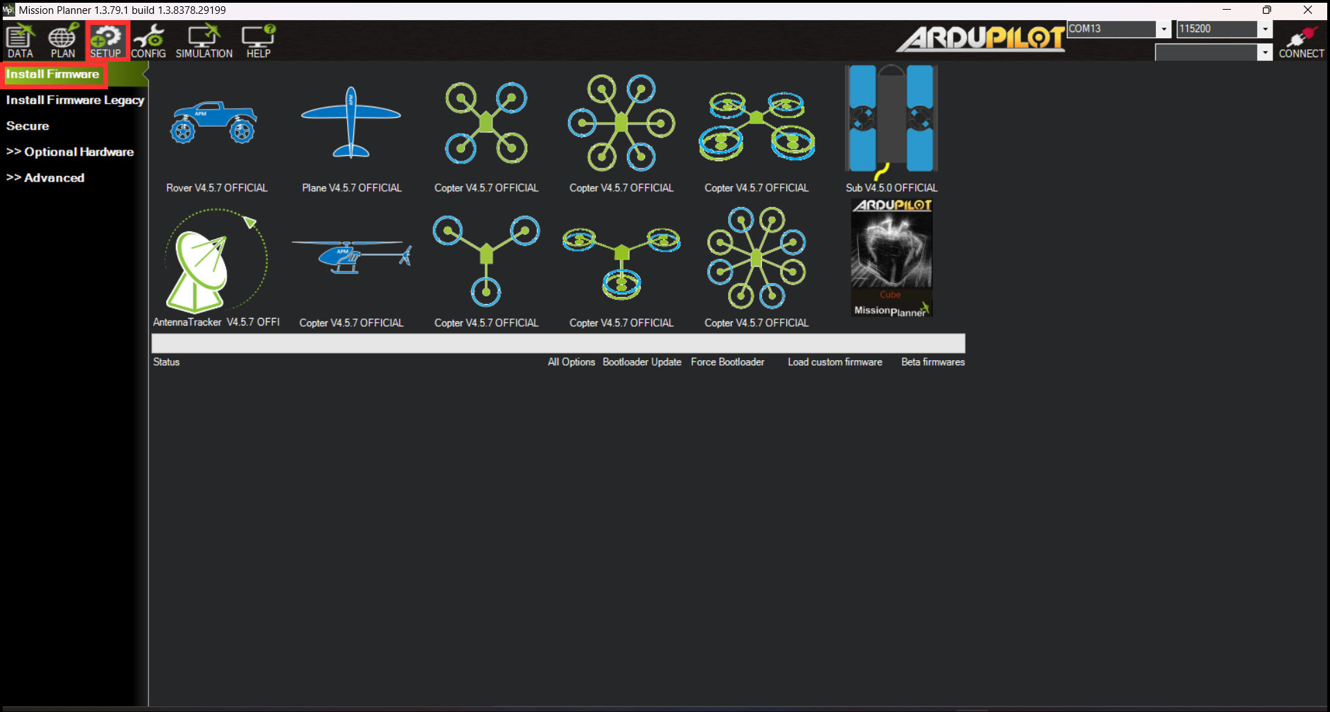
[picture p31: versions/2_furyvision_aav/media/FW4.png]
Select Setup tool
	

6. **Confirm Firmware Version**:
A popup will display the available firmware version. Click Yes to proceed.

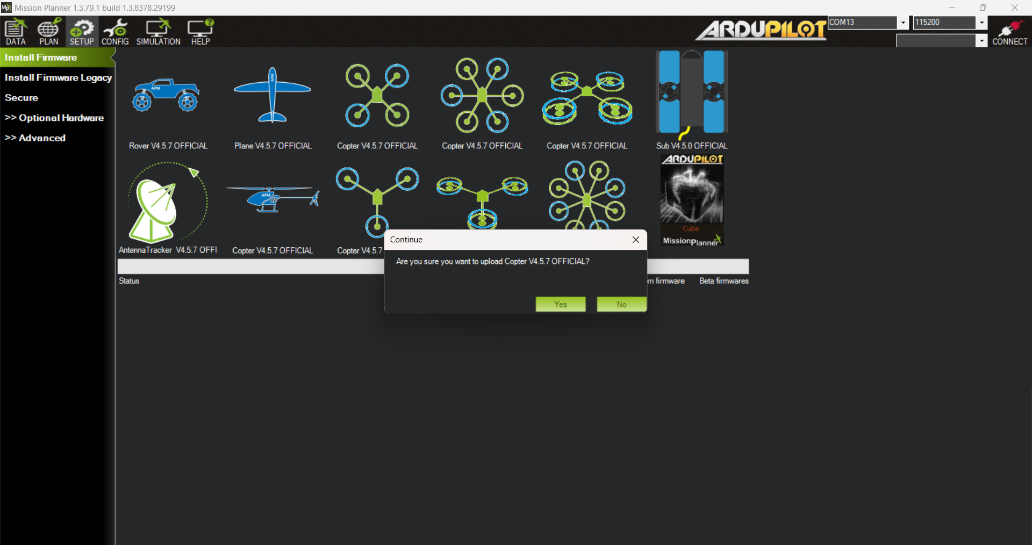
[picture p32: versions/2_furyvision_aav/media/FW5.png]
Cofirm to Update firmware version
	

7. **Select the Platform**: Use the dropdown menu to select the appropriate flight controller for your drone (e.g., Pixhawk, Cube Orange).

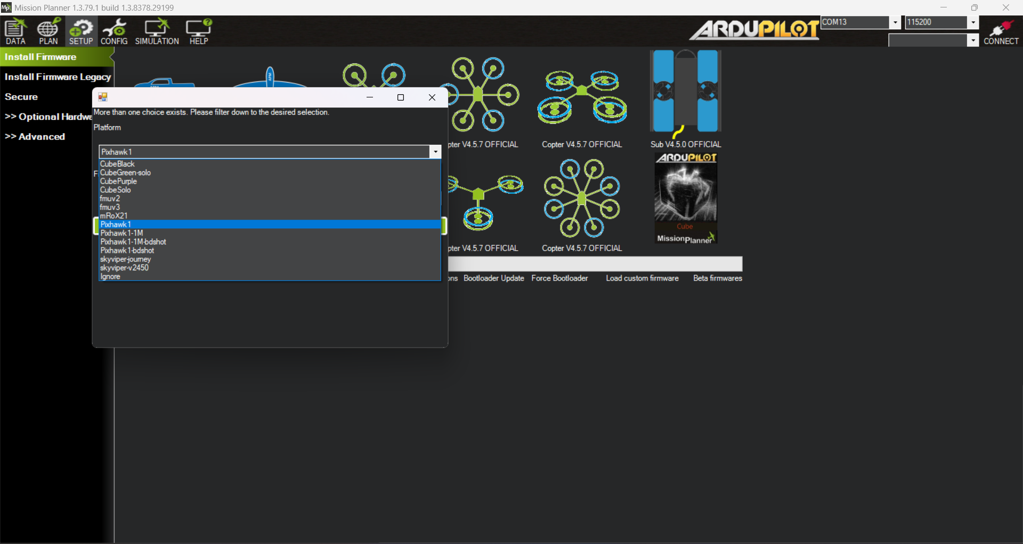
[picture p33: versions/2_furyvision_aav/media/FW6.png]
Select Flight controller
	
	 
8. **Upload Firmware**:
- Click to upload the firmware.
- Follow the on-screen instructions carefully to avoid errors.

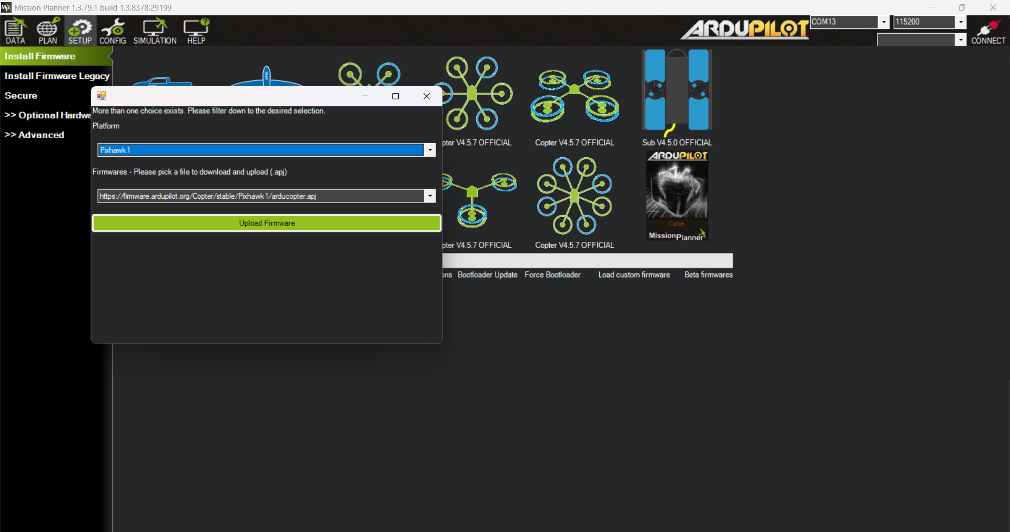
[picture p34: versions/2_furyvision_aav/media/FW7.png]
Click to upload firmware
	
9. **Follow the Instruction**: Carefully read and follow any additional popup messages for specific instructions during the process.

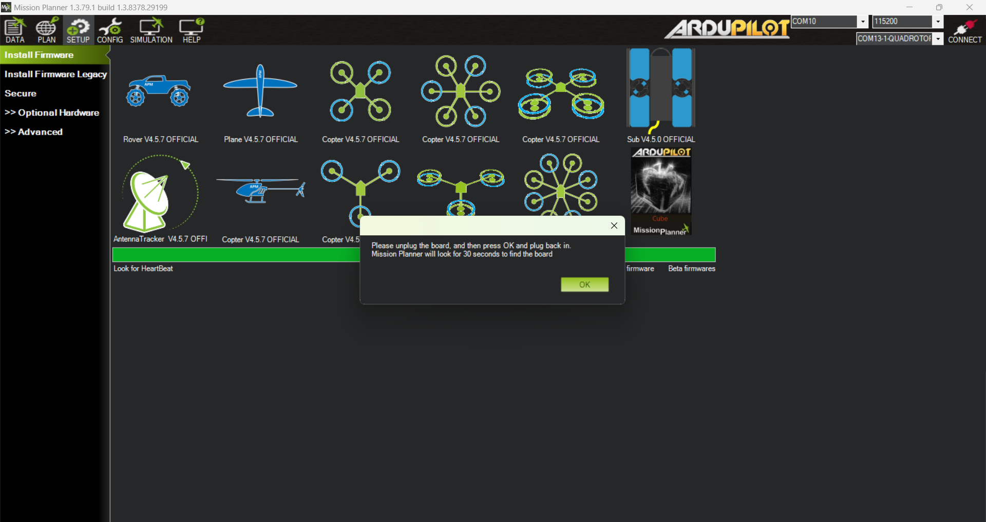
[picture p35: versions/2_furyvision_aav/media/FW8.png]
Popup Message
	

10. **Wait for Upload to Complete**:
Allow the upload process to finish without interruptions.

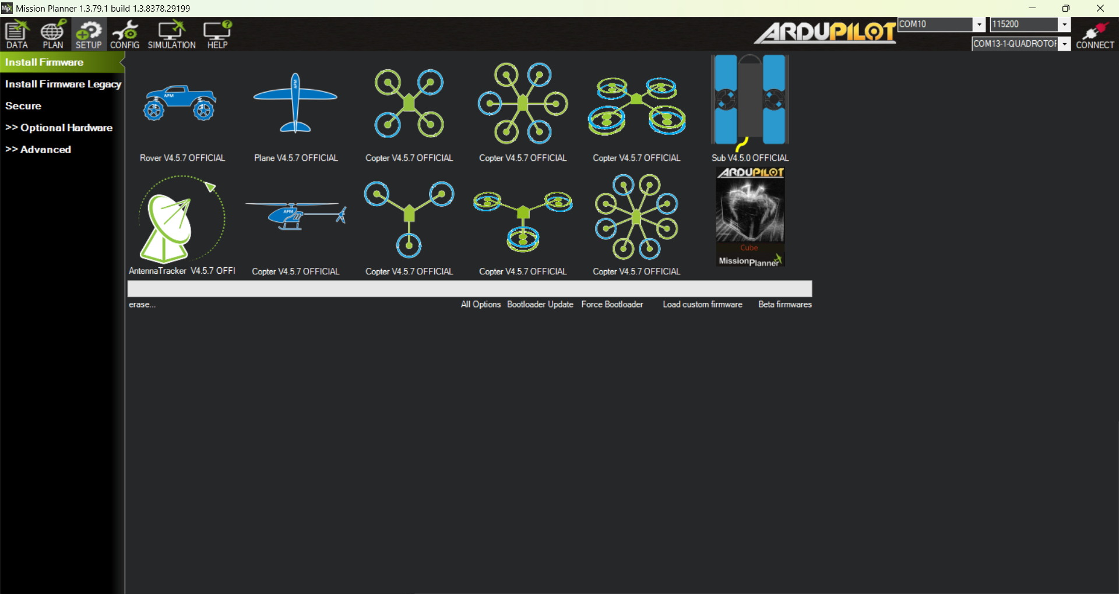
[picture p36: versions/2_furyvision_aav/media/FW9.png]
Processing
	

11. **Completion**:

- Once the update is complete, Mission Planner will display an "Upload Done" message.
- The flight controller will emit a beep sound to confirm the update.

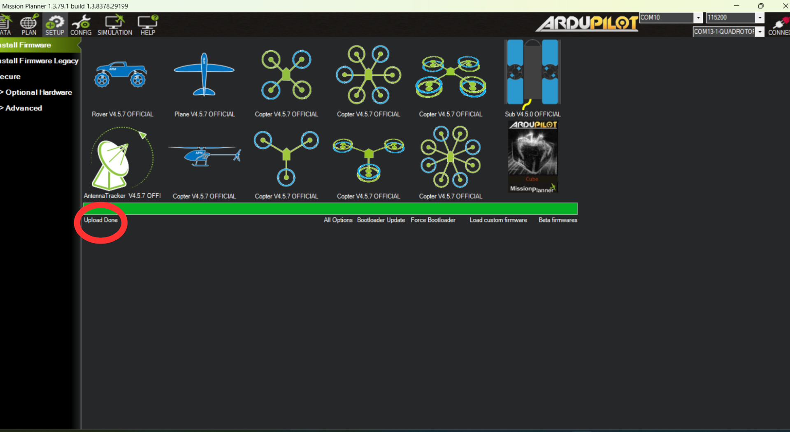
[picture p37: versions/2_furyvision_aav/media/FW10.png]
Upload Done
	
	
12. **Reboot the Flight Controller**:
Reboot the flight controller to apply the firmware update.
	
---

### Post-Update Tips
- Check the firmware version on your flight controller to ensure it matches the one you uploaded.
- Perform a basic system check to confirm all sensors and components are functioning correctly.
- If required, recalibrate sensors (e.g., accelerometer, compass).	
---
## Your firmware update is now complete!

Enjoy improved performance and new features on your drone. For further assistance, refer to the Mission Planner documentation or support forums.

**Referance: [Link](https://ardupilot.org/copter/docs/common-loading-firmware-onto-pixhawk.html)**

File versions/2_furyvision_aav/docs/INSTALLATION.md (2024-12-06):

# FuryVision AAV Drone Installation Guide

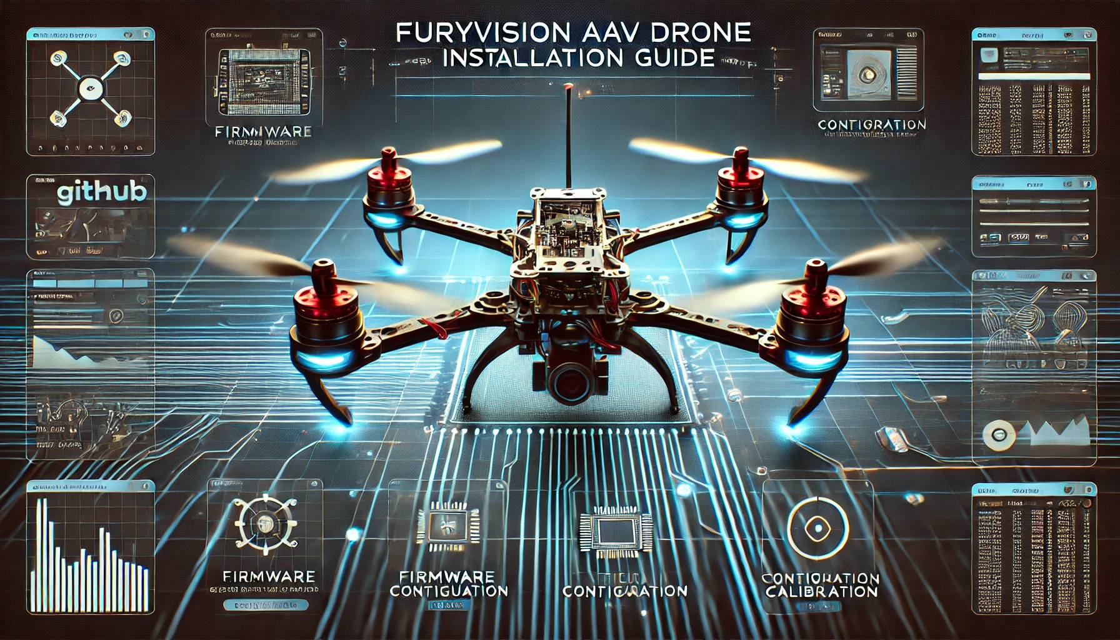
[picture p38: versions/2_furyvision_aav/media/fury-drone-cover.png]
FuryVision AAV AI


This guide provides an overview of the setup process for the **FuryVision AAV (v2)** drone, focusing on firmware installation, configuration, and calibration using **Mission Planner**. For detailed instructions on hardware assembly, please refer to the **Assembly Guide PDF** provided in the repository.

---

## Table of Contents

1. [Prerequisites](#1-prerequisites)
2. [Hardware Assembly](#2-hardware-assembly)
3. [Firmware Installation](#3-firmware-installation)
   - [Installing ArduCopter Firmware](#31-installing-arducopter-firmware)
   - [Uploading Tuned Parameters](#32-uploading-tuned-parameters)
4. [Mission Planner Configuration and Calibration](#4-mission-planner-configuration-and-calibration)
   - [Accelerometer Calibration](#41-accelerometer-calibration)
   - [Compass Calibration](#42-compass-calibration)
   - [Radio Calibration](#43--radio-channel-mapping-and-calibration)
   - [Changing Motor Outputs to Aux](#44-changing-motor-outputs-to-aux-pins)
   - [ESC Calibration using DShot](#45-esc-calibration-using-dshot)
5. [Testing](#5-testing)
   - [Motor Spinning Test](#51-motor-spinning-test)
   - [Flight Test](#52-flight-test)
6. [Bill of Materials (BOM)](#6-bill-of-materials-bom)
7. [Troubleshooting](#7-troubleshooting)

---

## 1. Prerequisites

Before proceeding, ensure you have the following:

- **Pixhawk Orange Cube+ flight controller**
- **Intel RealSense Cameras (if applicable)**
- **Here 3+ GPS module**
- **Emax brushless motors**
- **Holybro Tekko 4 in 1 ESC**
- **14.8V, 2200mAh LiPo battery**
- **Raspberry Pi 4 (optional)**
- **Propellers (5.0*5.5)**

You will also need:

- A computer with **Mission Planner** installed.
- **Screwdrivers**, **allen key set**, and **soldering equipment** (if required for motor/ESC wiring).

---

## 2. Hardware Assembly

For the complete step-by-step assembly process, including frame construction, motor and propeller installation, and camera mounting, please refer to the [**Assembly Guide (PDF)**](/versions/2_furyvision_aav/docs/Assembly%20of%20FuryVision%20AAV.pdf) located in the `docs/` folder of this repository.

---

## 3. Firmware Installation

### 3.1 Installing ArduCopter Firmware

1. Connect your **Pixhawk Orange Cube+** flight controller to your computer using a USB cable.
2. Open **Mission Planner** and navigate to the **Install Firmware** section.
3. Choose **ArduCopter** as the firmware and install **version 4.5.6 (7ce11b41)** or latest.
4. Wait for the installation to complete, and then reboot the Pixhawk.

**[Referance: Detailed ArduCopter Firmware Installation Guide](/versions/2_furyvision_aav/docs/FIRMWARE_GUIDE.md)**

### 3.2 Uploading Tuned Parameters

1. After the firmware is successfully installed, go to the **Configuration** tab in Mission Planner.
2. Select **Full Parameter List** and upload the pre-tuned parameter file from the `/firmware` folder (`fury_drone1.param`).
3. Verify that all parameters are loaded correctly and correspond to your specific setup.

---

## 4. Mission Planner Configuration and Calibration

To ensure optimal flight performance, you will need to calibrate various sensors and settings using **Mission Planner**.

### 4.1 Accelerometer Calibration

1. In Mission Planner, navigate to the **Initial Setup** tab.
2. Select **Accelerometer Calibration** and follow the on-screen instructions to calibrate the drone’s orientation and leveling.

   **Referance for Accelerometer Calibration: [Link](https://ardupilot.org/planner/docs/common-accelerometer-calibration.html)**

### 4.2 Compass Calibration

1. Go to **Initial Setup** > **Compass**.
2. Perform the compass calibration by rotating the drone in different orientations as prompted.

   - Make sure there is no significant magnetic interference during calibration.

   **Referance for Compass Calibration: [Link](https://ardupilot.org/planner/docs/common-compass-calibration-in-mission-planner.html)**

### 4.3  Radio Channel Mapping and Calibration

#### Radio Channel Mapping:

1. Power on the FlySky FS-i6 transmitter and enter the setup menu.
2. Navigate to Functions Setup > Aux Channels and map the channels as follows:
   - **Throttle:** Channel 3 (Joystick A)
   - **Pitch:** Channel 2 (Joystick B)
   - **Roll:** Channel 1 (Joystick B)
   - **Yaw:** Channel 4 (Joystick A)

     **Flight Modes:**

     - Stabilize: Channel 5 (SWC1)
     - Loiter: Channel 5 (SWC2)
     - AltHold: Channel 5 (SWC3)
   - **Arm/Disarm**: Channel 6 (SWA)

#### Binding the X6B Receiver:

1. Connect the **X6B receiver** to the Pixhawk via the i-BUS port.
2. Bind the **X6B receiver** to the transmitter following the FlySky binding procedure.

#### Radio Calibration in Mission Planner:

1. In Mission Planner, navigate to **Initial Setup > Radio Calibration.**
2. Follow the instructions to calibrate **Throttle, Pitch, Roll, Yaw**, and test the flight modes

   **Referance for Radio Calibration: [Link](https://ardupilot.org/planner/docs/common-radio-control-calibration.html)**

### 4.4 Changing Motor Outputs to Aux pins

To change motor outputs from `M1, M2, M3, M4` to `A1, A2, A3, A4`:

1. In Mission Planner, go to the **Full Parameter Tree/list**.
2. Locate the motor output parameters (`SERVO1_FUNCTION`, `SERVO2_FUNCTION`, etc.).
3. Update the SERVOX_FUNCTION values:
   - **A1:** `SERVO1_FUNCTION = 33`
   - **A2:** `SERVO2_FUNCTION = 34`
   - **A3:** `SERVO3_FUNCTION = 35`
   - **A4:** `SERVO4_FUNCTION = 36`
4. Save the parameters and reboot the Pixhawk.

### **Or else, this can done easily using Mission Planner’s `Servo Output` page**

- In Mission Planner, go to the **Initial Setup > Mandatory Hardware > Servo Output**.

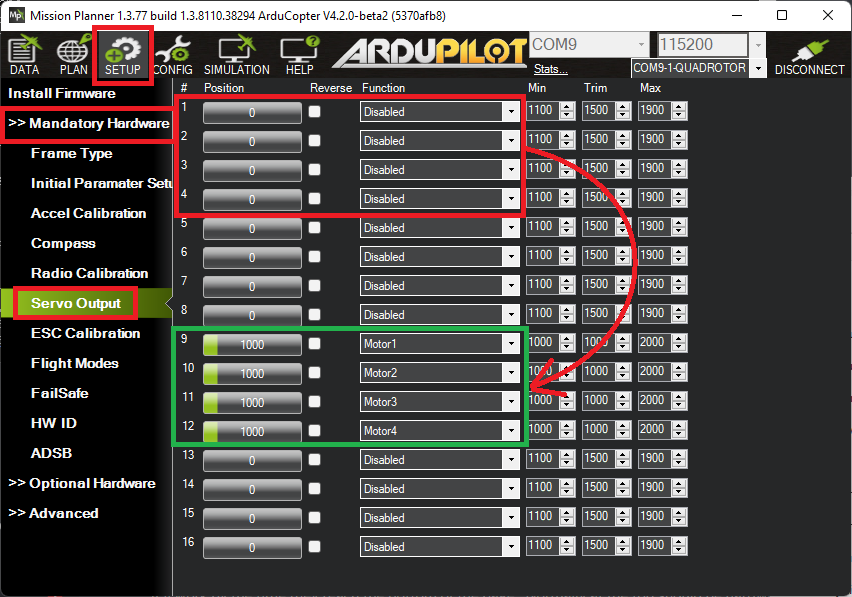
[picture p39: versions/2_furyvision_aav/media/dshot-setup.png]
DShot setup DShot setup in MissionPlanner


### 4.5 ESC Calibration using DShot

The **Holybro Tekko 4in1 ESC** supports **DShot** for digital motor control. Manual ESC calibration may not be necessary, but follow these steps to ensure correct setup:

1. In **Mission Planner**, go to **Initial Setup > Mandatory Hardware > ESC Calibration.**
2. Set **DShot** as the **ESC Protocol** under the **Motor Test** tab.
3. Ensure the motors are connected to **A1, A2, A3, A4** (instead of M1, M2, M3, M4).
4. Select the `DShot` appropriate `baud rate`.
5. Reboot the Pixhawk and test motor spin using the **Motor Test** function in Mission Planner.
6. Adjust **DShot settings** in **Mission Planner** as needed to fine-tune performance.

**Referance for Dshot ESC setup: [Link](https://ardupilot.org/copter/docs/common-dshot-escs.html)**

---

## 5. Testing

### 5.1 Motor Spinning Test

1. Use Mission Planner to perform a motor spinning test.
   - Go to **Optional Hardware** > **Motor Test** and ensure that all motors spin in the correct direction.
2. Verify that there are no unusual vibrations or noises during the test.

### 5.2 Flight Test

1. Conduct initial test flights in the following modes:
   - **Stabilize Mode**: Test the drone’s stability and control response.
   - **Altitude Hold Mode**: Verify altitude-hold functionality.
   - **Loiter Mode**: Test GPS-based position hold.
2. Monitor the drone’s performance and make any necessary adjustments based on flight logs.

---

## 6. Bill of Materials (BOM)

The complete **Bill of Materials (BOM)** for the FuryVision AAV can be found in the repository at the following location:

- [BOM for FuryVision AAV](/versions/2_furyvision_aav/hardware/BOM_furyvision_aav.pdf)

The BOM details all components used in the drone, including motors, sensors, flight controllers, and other hardware components.

---

## 7. Troubleshooting

If you encounter any issues during installation or calibration, consider the following:

- Ensure all firmware and parameter files are uploaded correctly.
- Double-check hardware connections (ESC, motors, GPS, etc.).
- Re-run calibration steps if the drone shows instability or drift during flight.
- Consult the [**TROUBLESHOOTING.md**](/versions/2_furyvision_aav/docs/TROUBLESHOOTING.md) file for additional guidance on common problems.

For more assistance, visit the project’s GitHub Issues page or contact the development team.

---

This guide focuses on the **firmware installation**, **Mission Planner configuration**, and **calibration** steps while referring users to the **detailed assembly PDF** for hardware instructions.

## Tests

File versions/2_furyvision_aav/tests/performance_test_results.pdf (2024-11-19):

## FuryVision AAV Performance Test

## ICFOSS, October 21, 2024

### 1. Frame & Build Integrity

1.1. Frame Integrity: Ensured no cracks, loose screws, or weak joints.
1.2. Motors: Verified all motors are securely attached and spin in the correct direction.

### 1.3. Propellers: Confirmed propellers are balanced, securely attached, and free of

damage.

### 1.4. Flight Controller (Pixhawk): Ensured the flight controller is securely mounted, with

all connections firm and correct.

### 1.5. Antenna(s): Confirmed the radio antennas are securely attached and positioned

orthogonally to minimize interference.

### 1.6. Battery Mount: Checked that the battery mounting mechanism is secure (strap or

case).

### 1.7. Camera Mount: Checked that the camera mounting mechanism is secure

### 2. Electronic & Wiring

### 2.1. ESC Wiring: Ensured ESC wiring is correct, solder joints are strong and provide

stability.

### 2.2. GPS/Compass Module: Confirmed correct positioning and wiring, ensuring no

electromagnetic interference.

### 2.3. Raspberry Pi Wiring (if applicable): Verified that all Raspberry Pi connections are

properly wired and secure.

### 3. Calibration & Testing

### 3.1. Accelerometer Calibration: Verified that the accelerometer is calibrated and

functioning properly.

### 3.2. Compass Calibration: Confirmed the compass is calibrated, with no significant

interference.
3.3. Radio Calibration: Ensured that the radio system is properly calibrated.

### 3.4. Motor Spinning Test: Perform a motor spinning test to verify all motors start and

stop correctly.

### 3.5. Flight Test: Conduct flight tests in the following modes, and note observations

(attach flight log):
■ Stabilize: For your reference, the flight log is attached in the folder test_logs under the folder name stabilize. The log files included are stabilize.tlog and stabilize.rlog.

■ Altitude Hold: For your reference, the flight log is attached in the folder test_logs under the folder name althold. The log files included are althold.tlog and althold.rlog.
■ Loiter: For your reference, the flight log is attached in the folder test_logs under the folder name loiter. The log files included are loiter.tlog and loiter.rlog.

### 4. Firmware & Tuning

4.1. Firmware Details: Upload the latest firmware and note the version details (e.g., ArduCopter)

Arducopter version: V4.5.6(7ce11b41)

### 4.2. Parameter Copy: Attach a copy of all tuned parameters after flight tuning for

reference.
Note: For your reference, a copy of all tuned parameters is attached in the folder parameter with the file name fury_drone1.param.

### 5. Weight & Flight Time

### 5.1. All-Up Weight:

■ Weight with battery: The all-up weight of 1161g includes the Fury frame, battery, 4 cameras and its mounting parts
■ Weight without battery: The all-up weight of 923g includes the Fury frame, 4 cameras and its mounting parts

### 5.2. Observed Flight Time: Record the flight time during tests and mention the battery

used (capacity, voltage).
Battery Voltage: 14.8V
Battery Capacity: 2200mAh

Test: Flight test to determine the flight time with an RTL voltage of 3.3V per cell. The all-up weight of 932g includes the Here GPS module, battery, and Fury frame.

Individual Cell | Before Flying | After Flying
Cell1 | 4.13V | 3.41V
Cell2 | 4.12V | 3.37V
Cell3 | 4.14V | 3.39V
Cell4 | 4.13V | 3.42V
Total Cell Voltage | 16.15V | 13.5V

Flight Time ( up to landing): 8 minutes and 40 seconds

Note: For your reference, the flight log is attached in the folder test_logs under the folder name flighttime_test. The log files included are test.tlog and test.rlog.

### 6. Performance & Observations

6.1. Motor Thrust Chart: Include the motor thrust chart, if possible.

### 6.2. Remote Controller Channel Mapping: Provide details of the remote controller

channel mapping (throttle, pitch, roll, yaw).

| | Channels | Switch
Flight Controls | Throttle | Channel 3 | Joystick A
| Pitch | Channel 2 | Joystick B
| Roll | Channel 1 | Joystick B
| Yaw | Channel 4 | Joystick A
Flight Modes | Stabilize | Channel 5 | SWC1
| Loiter | Channel 5 | SWC2
| Althold | Channel 5 | SWC3
Arm / Disarm | Arm | Channel 6 | SWA
| Disarm | Channel 6 | SWA

### 6.3. Temperature After Hovering Test:

Test: Determine the temperature of the components (motors and ESC) before and after flying.

Items | Temperature Before Flying | Temperature After Flying
Motor1(M1) | 31.1° C | 44.9° C
Motor2(M2) | 31° C | 43.5° C
Motor3(M3) | 30.2° C | 43.2° C
Motor4(M4) | 31° C | 44.5° C
ESC | 29° C | 43.2° C

### 6.4. Temperature on Ground (after 5 minutes of powering):

Individual motor temperatures:

Motors | Temperature Before Powering | Temperature After 5 minutes of Powering
Motor1(M1) | 31° C | 31.5° C
Motor1(M2) | 32.2° C | 31.7° C
Motor1(M3) | 30.8° C | 31.7° C
Motor1(M4) | 30.7° C | 317° C
ESC | 29.6° C | 35.5° C

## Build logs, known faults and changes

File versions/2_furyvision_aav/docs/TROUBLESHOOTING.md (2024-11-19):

# **FuryVision AAV Drone - Troubleshooting Guide**

This guide addresses common issues encountered during assembly, firmware installation, calibration, and flight, and provides actionable solutions to resolve them.

---

## **Table of Contents**
1. [Firmware and Parameter Issues](#1-firmware-and-parameter-issues)
2. [Radio Calibration Issues](#2-radio-calibration-issues)
3. [ESC and Motor Issues](#3-esc-and-motor-issues)
4. [Sensor Calibration Issues](#4-sensor-calibration-issues)
5. [Flight Issues](#5-flight-issues)
6. [Camera and Sensor Integration Issues](#6-camera-and-sensor-integration-issues)
7. [General Hardware Issues](#7-general-hardware-issues)
8. [Additional Resources](#8-additional-resources)

---

## **1. Firmware and Parameter Issues**

### **1.1 Firmware Upload Fails**
- **Problem**: Mission Planner cannot detect the Pixhawk or fails to upload firmware.
  - **Solution**:
    1. Ensure the USB cable is securely connected to the Pixhawk and computer.
    2. Use a different USB port or cable if the issue persists.
    3. Reboot the Pixhawk and try again.
    4. Verify that the correct firmware type (ArduCopter) is selected.

### **1.2 Parameter Upload Fails**
- **Problem**: Tuned parameter file does not load or fails to apply changes.
  - **Solution**:
    1. Ensure the `.param` file is correct and complete.
    2. Reload the parameter file from the **Full Parameter List** in Mission Planner.
    3. Manually verify and adjust any missing parameters.

---

## **2. Radio Calibration Issues**

### **2.1 Transmitter Not Responding**
- **Problem**: The FlySky FS-i6 transmitter inputs are not recognized.
  - **Solution**:
    1. Verify that the transmitter and X6B receiver are properly bound.
    2. Check the connection between the X6B receiver and Pixhawk (i-BUS port).
    3. Power cycle the transmitter and receiver.

### **2.2 Incorrect Channel Mapping**
- **Problem**: Flight modes or controls do not behave as expected.
  - **Solution**:
    1. Confirm that the transmitter’s channel mapping matches the drone’s configuration:
       - Throttle: Channel 3
       - Pitch: Channel 2
       - Roll: Channel 1
       - Yaw: Channel 4
       - Flight Modes: Channel 5
    2. Recalibrate the radio in Mission Planner.

---

## **3. ESC and Motor Issues**

### **3.1 Motor Does Not Spin**
- **Problem**: One or more motors fail to spin during the motor test.
  - **Solution**:
    1. Check the ESC wiring for loose connections.
    2. Ensure the motor outputs (A1, A2, A3, A4) are correctly mapped in the **Full Parameter Tree**.
    3. Verify that the ESC protocol is set to **DShot**.

### **3.2 Incorrect Motor Direction**
- **Problem**: A motor spins in the wrong direction.
  - **Solution**:
    1. Reverse the motor wiring by swapping any two wires connected to the motor.
    2. Use Mission Planner’s **Motor Test** to confirm proper motor rotation.

---

## **4. Sensor Calibration Issues**

### **4.1 Accelerometer Calibration Fails**
- **Problem**: Calibration does not complete or the drone behaves erratically.
  - **Solution**:
    1. Ensure the drone is placed on a flat, stable surface during calibration.
    2. Reboot the Pixhawk and retry the calibration.

### **4.2 Compass Calibration Fails**
- **Problem**: Compass calibration shows interference or fails to complete.
  - **Solution**:
    1. Check for nearby magnetic interference during calibration.
    2. Move the GPS/compass module away from power wires and other electronics.
    3. Perform a **compass-motor calibration** to account for magnetic interference from motors.

---

## **5. Flight Issues**

### **5.1 Drone Drifts in Stabilize Mode**
- **Problem**: The drone does not maintain its position and drifts excessively.
  - **Solution**:
    1. Recalibrate the accelerometer and compass.
    2. Check for loose propellers or motors.

### **5.2 Drone Fails to Maintain Altitude**
- **Problem**: The drone oscillates or struggles to hold altitude.
  - **Solution**:
    1. Ensure the barometer is not exposed to direct airflow or light.
    2. Verify battery voltage; a low battery can affect performance.

### **5.3 GPS-Related Issues**
- **Problem**: Drone fails to hold position in Loiter mode.
  - **Solution**:
    1. Ensure the GPS has a strong lock (minimum 8 satellites).
    2. Reposition the GPS module for optimal signal reception.

---

## **6. Camera and Sensor Integration Issues**

### **6.1 Intel RealSense Camera Not Detected**
- **Problem**: RealSense cameras are not recognized by the onboard system.
  - **Solution**:
    1. Verify the USB connection to the onboard computer.
    2. Ensure the RealSense ROS package is installed and configured correctly.

### **6.2 Poor Camera Performance**
- **Problem**: Cameras experience frame drops or poor image quality.
  - **Solution**:
    1. Check that the onboard computer has sufficient processing power.
    2. Use a high-quality USB cable and verify connections.

---

## **7. General Hardware Issues**

### **7.1 Loose or Faulty Connections**
- **Problem**: Components (motors, GPS, cameras) are not responsive.
  - **Solution**:
    1. Inspect all wiring and connectors for secure connections.
    2. Check solder joints on ESCs and motors.

### **7.2 Frame Vibration Issues**
- **Problem**: Excessive vibrations affect flight stability.
  - **Solution**:
    1. Tighten all screws and mounts on the frame.
    2. Add vibration dampeners between the frame and the Pixhawk.

---

## **8. Additional Resources**

- Refer to the [Mission Planner Documentation](https://ardupilot.org/planner/) for advanced configurations.
- Consult the [ArduPilot Forums](https://discuss.ardupilot.org/) for community support.
- Visit the project’s GitHub Issues page for additional troubleshooting.

---

This guide addresses a range of issues you might encounter during the installation and operation of the **FuryVision AAV Drone**. Let me know if you'd like to expand or modify this further!

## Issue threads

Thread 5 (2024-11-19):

Performance Test Result document missing in test/ folder

sidharthmohannair, 2024-11-19:
### Description
The Performance Test Result document is missing from the `test/` folder. This document is essential for logging and analyzing the drone's performance during various tests such as flight duration, motor efficiency, and component temperatures.

### Expected Behavior
- A `performance_test_results.md` file should exist in the `test/` folder, documenting detailed test results, including:
  - Motor thrust data
  - Battery performance
  - Temperature readings during flight
  - Flight duration logs

sidharthmohannair, 2024-11-19:
issue resolved #6

Closed 2024-11-19.

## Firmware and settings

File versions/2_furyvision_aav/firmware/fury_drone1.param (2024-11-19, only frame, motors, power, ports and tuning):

ATC_ANG_LIM_TC,1
ATC_ANG_PIT_P,4.5
ATC_ANG_RLL_P,4.5
ATC_ANG_YAW_P,4.5
ATC_ANGLE_BOOST,1
ATC_RAT_PIT_D,0.0036
ATC_RAT_PIT_D_FF,0
ATC_RAT_PIT_FF,0
ATC_RAT_PIT_FLTD,37.5
ATC_RAT_PIT_FLTE,0
ATC_RAT_PIT_FLTT,37.5
ATC_RAT_PIT_I,0.135
ATC_RAT_PIT_IMAX,0.5
ATC_RAT_PIT_NEF,0
ATC_RAT_PIT_NTF,0
ATC_RAT_PIT_P,0.135
ATC_RAT_PIT_PDMX,0
ATC_RAT_PIT_SMAX,0
ATC_RAT_RLL_D,0.0036
ATC_RAT_RLL_D_FF,0
ATC_RAT_RLL_FF,0
ATC_RAT_RLL_FLTD,37.5
ATC_RAT_RLL_FLTE,0
ATC_RAT_RLL_FLTT,37.5
ATC_RAT_RLL_I,0.135
ATC_RAT_RLL_IMAX,0.5
ATC_RAT_RLL_NEF,0
ATC_RAT_RLL_NTF,0
ATC_RAT_RLL_P,0.135
ATC_RAT_RLL_PDMX,0
ATC_RAT_RLL_SMAX,0
ATC_RAT_YAW_D,0
ATC_RAT_YAW_D_FF,0
ATC_RAT_YAW_FF,0
ATC_RAT_YAW_FLTD,0
ATC_RAT_YAW_FLTE,2
ATC_RAT_YAW_FLTT,37.5
ATC_RAT_YAW_I,0.018
ATC_RAT_YAW_IMAX,0.5
ATC_RAT_YAW_NEF,0
ATC_RAT_YAW_NTF,0
ATC_RAT_YAW_P,0.18
ATC_RAT_YAW_PDMX,0
ATC_RAT_YAW_SMAX,0
ATC_RATE_FF_ENAB,1
ATC_RATE_P_MAX,0
ATC_RATE_R_MAX,0
ATC_RATE_Y_MAX,0
BATT_AMP_OFFSET,0
BATT_AMP_PERVLT,39.877
BATT_ARM_MAH,0
BATT_ARM_VOLT,14.7
BATT_CAPACITY,2200
BATT_CRT_MAH,0
BATT_CRT_VOLT,14
BATT_CURR_PIN,15
BATT_FS_CRT_ACT,0
BATT_FS_LOW_ACT,2
BATT_FS_VOLTSRC,0
BATT_LOW_MAH,0
BATT_LOW_TIMER,10
BATT_LOW_VOLT,14.4
BATT_MONITOR,4
BATT_OPTIONS,0
BATT_SERIAL_NUM,-1
BATT_VLT_OFFSET,0
BATT_VOLT_MULT,12.02
BATT_VOLT_PIN,14
BATT2_MONITOR,0
BATT3_MONITOR,0
BATT4_MONITOR,0
BATT5_MONITOR,0
BATT6_MONITOR,0
BATT7_MONITOR,0
BATT8_MONITOR,0
BATT9_MONITOR,0
FLTMODE_CH,5
FLTMODE_GCSBLOCK,0
FLTMODE1,0
FLTMODE2,0
FLTMODE3,0
FLTMODE4,5
FLTMODE5,0
FLTMODE6,2
FRAME_CLASS,1
FRAME_TYPE,1
INS_GYRO_FILTER,75
INS_HNTCH_ENABLE,0
MOT_BAT_CURR_MAX,0
MOT_BAT_CURR_TC,5
MOT_BAT_IDX,0
MOT_BAT_VOLT_MAX,16.8
MOT_BAT_VOLT_MIN,13.2
MOT_BOOST_SCALE,0
MOT_HOVER_LEARN,2
MOT_OPTIONS,0
MOT_PWM_MAX,2000
MOT_PWM_MIN,1000
MOT_PWM_TYPE,7
MOT_SAFE_DISARM,0
MOT_SAFE_TIME,1
MOT_SLEW_DN_TIME,0
MOT_SLEW_UP_TIME,0
MOT_SPIN_ARM,0.1
MOT_SPIN_MAX,0.95
MOT_SPIN_MIN,0.15
MOT_SPOOL_TIM_DN,0
MOT_SPOOL_TIME,0.5
MOT_THST_EXPO,0.55
MOT_THST_HOVER,0.1635952
MOT_YAW_HEADROOM,200
SERIAL0_BAUD,115
SERIAL0_PROTOCOL,2
SERIAL1_BAUD,57
SERIAL1_OPTIONS,0
SERIAL1_PROTOCOL,2
SERIAL2_BAUD,57
SERIAL2_OPTIONS,0
SERIAL2_PROTOCOL,2
SERIAL3_BAUD,230
SERIAL3_OPTIONS,0
SERIAL3_PROTOCOL,5
SERIAL4_BAUD,230
SERIAL4_OPTIONS,0
SERIAL4_PROTOCOL,5
SERIAL5_BAUD,57
SERIAL5_OPTIONS,0
SERIAL5_PROTOCOL,1
SERIAL6_BAUD,115200
SERIAL6_OPTIONS,0
SERIAL6_PROTOCOL,22
SERVO1_FUNCTION,0
SERVO1_MAX,1900
SERVO1_MIN,1100
SERVO1_REVERSED,0
SERVO1_TRIM,1500
SERVO2_FUNCTION,0
SERVO2_MAX,1900
SERVO2_MIN,1100
SERVO2_REVERSED,0
SERVO2_TRIM,1500
SERVO3_FUNCTION,0
SERVO3_MAX,1900
SERVO3_MIN,1100
SERVO3_REVERSED,0
SERVO3_TRIM,1500
SERVO4_FUNCTION,0
SERVO4_MAX,1900
SERVO4_MIN,1100
SERVO4_REVERSED,0
SERVO4_TRIM,1500
SERVO5_FUNCTION,0
SERVO5_MAX,1900
SERVO5_MIN,1100
SERVO5_REVERSED,0
SERVO5_TRIM,1500
SERVO6_FUNCTION,0
SERVO6_MAX,1900
SERVO6_MIN,1100
SERVO6_REVERSED,0
SERVO6_TRIM,1500
SERVO7_FUNCTION,0
SERVO7_MAX,1900
SERVO7_MIN,1100
SERVO7_REVERSED,0
SERVO7_TRIM,1500
SERVO8_FUNCTION,0
SERVO8_MAX,1900
SERVO8_MIN,1100
SERVO8_REVERSED,0
SERVO8_TRIM,1500
SERVO9_FUNCTION,33
SERVO9_MAX,2000
SERVO9_MIN,1000
SERVO9_REVERSED,0
SERVO9_TRIM,1000

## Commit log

2024-10-25 original_fury updated
    [Landing_Gear_Prototype.stl.stl, PLA spacer for final carbon fibre plate.stl, electronics mount plate.stl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]
2024-10-25 BoM updated
2024-11-16 Fury Drone Assembly Documentation Updated
2024-11-16 Added all CAD and STL files
    [Base Plate.dxf, Base Plate.step, Flight controller holder.stl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]
2024-11-19 Updated the readme file and updated the installation guide
    [fury_drone1.param]
